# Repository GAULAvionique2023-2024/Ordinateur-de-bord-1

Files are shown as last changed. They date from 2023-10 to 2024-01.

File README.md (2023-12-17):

# ODB 1

## Description of the flight computer 1:
This board is an updated version of the first flight controler with little extra. So basicly I copy the old desing that it was an arduino shield and made it a standalone board. All the sensor is part of the board too, so no more module.All this help to make a board much smaller and more reliable. In extra I add a latching circuit too arme the board. You need to hold the button 3sec to power up the circuit and same thing to power it off. All switching is made with an mosfet so no mecanical switching excluding the power button. So the vibration can't make or break a connection and this is why the push button have an latching circuit, too avoid a false triger. Moreover I add a circuit too datalog the data on an SD card,I made a test circuit to test the 2 pyro. The circuit pass a little current (40mA) in the fuse and we mesure the voltage after so we can test for a short or open fuse. We can use this same circuit after to valid an ignition. I also add a logic circuit too avoid to put main power in the pyro when we trigger the test. It need 2 mosfet to be activate to ignite the fuse. A buzzer and a led status is also added. The board is powerd by a usb or lipo 1S(3.7v) that it can be charge by usb on the board. The RFD900 is powered by usb if its available but we will not be able to use full power only on usb so this is for testing only, on normal condition we will use an lipo 3S(11.1v). The pyro is powered by an lipo 4S(14.8v).

## Update log

### 23/12/16
All the test is now done. I corrected some mistake and change the status LED for an RGB one so it will be easier to understand its meaning. The new board its on the way.

### 23/11/22
Long time no see. Well I receive the board and do some test. All work except the GYRO and the inition of the fuse need to be confirm. I think I broke the gyro when I solder it so am waiting for a new one and in the same time im waiting for some e-fuse. I also made some minor change in the schematic and the board desing. Like switching the green status led by an RGB led, so it will be easyer to understand some status.  

### 23/10/09
Now the pcb is finish. I add the BOM file and the pcb is now on production.(see image: [ODB1_PCB](https://github.com/GAULAvionique2023-2024/Ordinateur-de-bord-1/blob/main/Images/ODB1_PCB.png))

### 23/10/01
So I rework the schematic to use less components and had the crystal circut, cause I dont know how but I was forgeting it. I also begin to layout the components on the pcb (see image: [OBD1_1_10_23](https://github.com/GAULAvionique2023-2024/Ordinateur-de-bord-1/blob/main/Images/OBD1_1_10_23.png)). I try my best to fit in the 85mmx85mm.

### 23/09/23
I add the possibility to use the RFD900 with the USB.

### 23/09/22
I can say that the schematic is now done but it will need to be verified to but sure that everything is ok and avoid poor mistake.
1.Redesing of the logic circuit protection to be more secure
2.Add a different batteries for the RFD900 so if the RFD900 drain it the pyro still have its own power.
3.In link with the second point, now the pyro is on 4s lipo (14.8v)

### 23/09/17
The schematic is almost done. Need to retink of some part of the logic part to protect the pyro cause it look like it can cause an oscilation (this part is not even up to date)
1.Add a buzzer.
2.Add poly fuse.
3.Add the logic circuit to protect the pyro. (see note on top)
4.Add latching circuit. (Hold 3s to power on/off)
5.Add many status leds. (one led can be placed externaly by a screw terminal)

This week I will try to list all the feature of this board, finalyze the schematic, add the data sheets of some ICs.

## Features
* Standalone board
* Powered by usb or lipo 1S
* Lipo charger in board
* Self test on igniter
* 2 ignitions circuits
* Gyro/Baro in board
* SD card for dataloging
* Latching circuit for powered the circuit
## Documentation
This is a list of documentation for the Ic

* [STM32F103C8](https://www.st.com/resource/en/datasheet/stm32f103c8.pdf) Main  microcontroller
* [ICM-20602](https://invensense.tdk.com/wp-content/uploads/2016/10/DS-000176-ICM-20602-v1.0.pdf) High Performance 6-Axis MEMS
* [BMP280](https://www.bosch-sensortec.com/media/boschsensortec/downloads/datasheets/bst-bmp280-ds001.pdf) Digital pressure sensor
* [L76L-M33](https://github.com/ul-gaul/Nebula-2022-2023/blob/cef41a131481a57f440abe9ede77973086518a58/WIP/Documentation/Quectel_L76_Series_Hardware_Design_V3.1.pdf) GNSS Module (GPS)
* [GT-0930RP2](https://github.com/ul-gaul/Nebula-2022-2023/blob/aa67e142a6133a87d8f8f1008be1e9982ea42536/WIP/Documentation/GT-0930RP2-14-Feb-2019.pdf) Buzzer
* [HM-10](https://github.com/ul-gaul/Nebula-2022-2023/blob/aa67e142a6133a87d8f8f1008be1e9982ea42536/WIP/Documentation/11.%20HM10%20BLE_FTDI.pdf)  BLE Module
* [TPS61201DRCR](https://www.ti.com/lit/ds/symlink/tps61201.pdf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)  Low Input Voltage Synchronous Boost Converter
* [LM1085](https://www.ti.com/lit/ds/symlink/lm1085.pdf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) 3-A Low Dropout Positive Regulators
* [max1898eub42+T](https://www.analog.com/media/en/technical-documentation/data-sheets/max1898.pdf) Linear Charger for Single-Cell Li+ Battery
* [LTC2954ITS8-1](https://www.analog.com/media/en/technical-documentation/data-sheets/2954fb.pdf) Pushbutton On/Off Controller with µP Interrup
* [CD74HC4051-EP](https://www.ti.com/lit/ds/symlink/cd74hc4051-ep.pdf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) Analog Multiplexer and Demultiplexer
* [74HC2G86DP_125](https://assets.nexperia.com/documents/data-sheet/74HC_HCT2G86.pdf) Dual 2-input EXCLUSIVE-OR gate
* [74HC2G86DP_125](https://assets.nexperia.com/documents/data-sheet/74HC_HCT2G08.pdf) Dual 2-input AND gate
* [74HC2G86DP_125](https://assets.nexperia.com/documents/data-sheet/74LVC2G02.pdf) Dual 2-input NOR gate

## Authors
List of authors
- [@Luka Dupuis](https://github.com/bestrider14)

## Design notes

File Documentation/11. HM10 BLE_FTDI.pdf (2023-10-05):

# Getting Started with the HM-10 BLE Module

### Working with the HM-10 BLE Module using UART

## Jarrod Smith

Department of Electrical and Computer Engineering

California State University, Fresno

NSF Bulldog Mote Team

## Contents

1 HM-10 BLE Module Serial Communication | 3

## List of Figures

1 | HM-10 Module from DSD Tech | | 3
2 | HM-10 Pins | | 3
3 | SH-U09F FTDI Module | | 4
4 | UART Communication Configuration | | 5
5 | Selecting Device Manager from the Start Menu | | 6
6 | Device Manager | | 7
7 | Realterm: Serial Monitor when it first starts | | 8
8 | Realterm Port Settings for FTDI Device | | 8
9 | Successful FTDI Communication in Realterm | | 9
10 | Master Discovery Readings | | 12
11 | Master (Bulldogs2) and Slave (Bulldogs) Devices Connected | | 13
12 | Master and Slave Sending Strings | | 14
13 | Master Connecting to Slave Based on MAC Address | | 15
14 | Bluetooth Adapter Disabled | | 17
15 | Scanning for BLE Devices | | 18
16 | HM-10 Services | | 19
17 | HM-10 ESS Characteristics | | 20
18 | Sending Temperature Data | | 21
19 | Temperature Reading in nRF Connect | | 22

## 1 HM-10 BLE Module Serial Communication

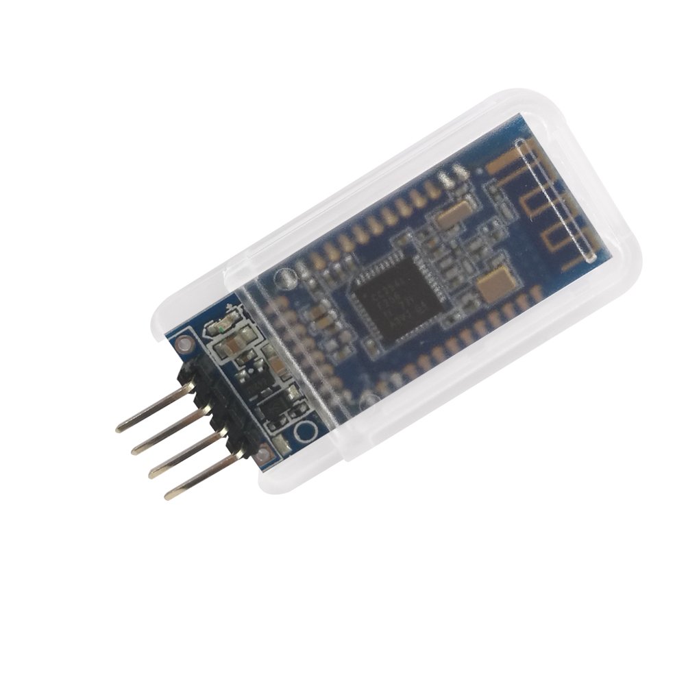
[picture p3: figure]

Figure 1: HM-10 Module from DSD Tech

The HM-10 Module is a Bluetooth 4.0 Module that includes Bluetooth Low Energy (BLE). This module transmits over the 2.4 GHz ISM band like traditional Bluetooth, however BLE uses considerably less power while still maintaining its effective communication range. This makes BLE a viable option for IoT communication between devices.

### 1.1 Overview

The BLE device communicates with a host microcontroller using UART. Depending on the supplier the device is purchased through will determine the number of pins. For this tutorial, the four middle pins will be used: RXD, TXD, GND and VDD.

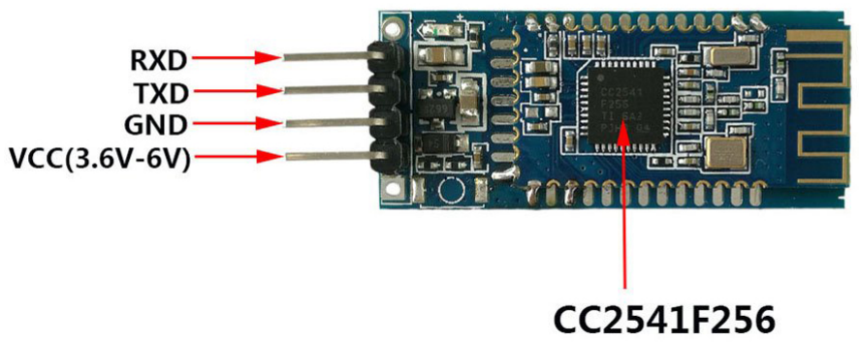
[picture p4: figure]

Figure 2: HM-10 Pins

The commands to control this device have to be understood before it is plugged into a microcontroller. To do this, an FTDI module can be used to connect the UART pins of the HM-10 directly to a computer. There, a serial connection can be established with the module and will give the user an easier time testing and debugging commands.

Any FTDI module will work, but be sure to purchase one with a genuine FTDI chip. Most computers have firmware installed already that will make these devices plug-and-play ready. However if the FTDI chip is not a genuine one, the modern firmware will be able to tell and “.*” the counterfeit chip, rendering it unusable.

The FTDI component used here is the SH-U09F, produced by DSD Tech as well.

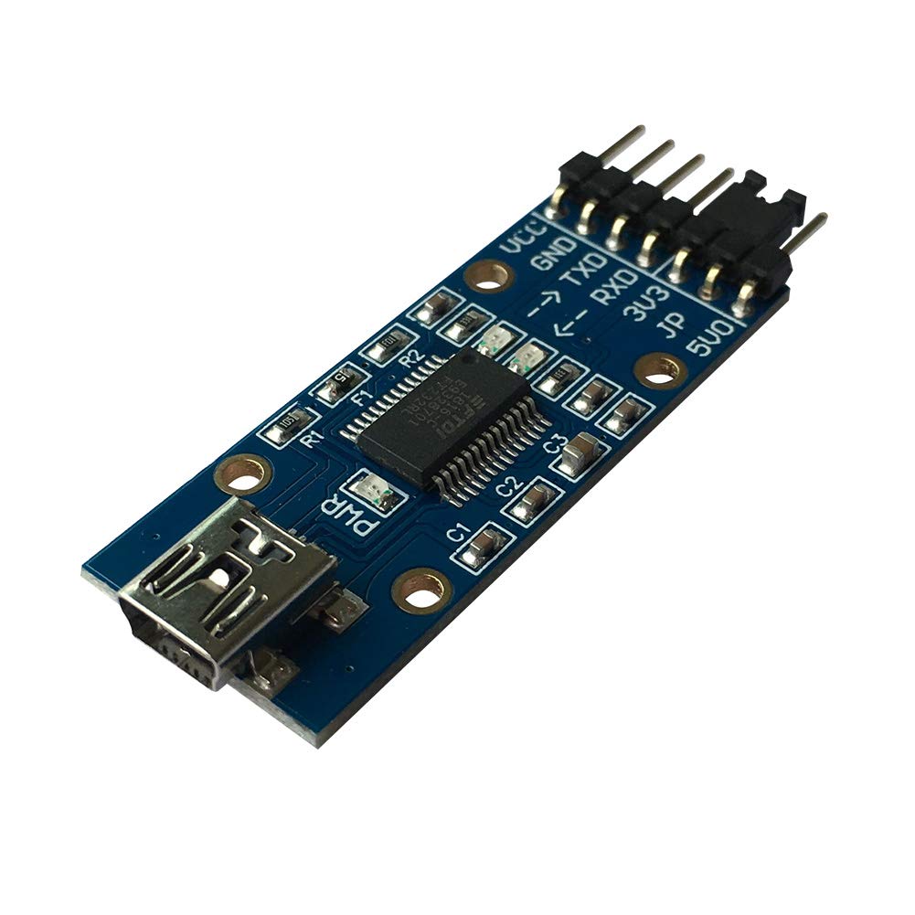
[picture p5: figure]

Figure 3: SH-U09F FTDI Module

The current drivers should be downloaded and installed before plugging the FTDI component into the computer. The current FTDI drivers can be found at http://www.ftdichip.com/Drivers/VCP.htm. (http://www.ftdichip.com/Drivers/VCP.htm) There you can select the correct firmware for your operating system. Once installed plug the device into your computer. The SH-U09F module here uses a micro USB cable to connect to the host computer.

After the computer finishes configuring the FTDI module, unplug the device. Next the FTDI module will be connected to the BLE module. The HC-10 device uses 3.3 V logic and power, so on the SH-U09F module the jumper between the 5V0 pin and JP pin should be changed to connect the 3V3 and JP pins instead. This changes the logic and VCC voltages to 3.3 V. Next, the pins of the devices can be connected with jumper wire. The following diagram should be followed:

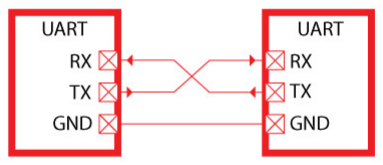
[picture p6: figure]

Figure 4: UART Communication Configuration

In UART communication, the receive line (Rx) on one device is connected to the transmit (Tx) of the other, and visa-versa. VCC and GND should also be connected.

Once connected a serial communication program can be used to send and receive data from the user’s computer to the end device on the other end of the FTDI module. The program used here to send and receive the UART data is Realterm: Serial Terminal: https://realterm.sourceforge.io/index.html#downloads_Download. Go to the link and click the download link at the top of the page to get the install executable.

Once installed and opened, the program will connect automatically to a device with a COM port. So plug in the FTDI module again, then open the Device Manager by clicking the Start menu, then type Device Manager in the Search text box. Open the Device Manager once it pops up.

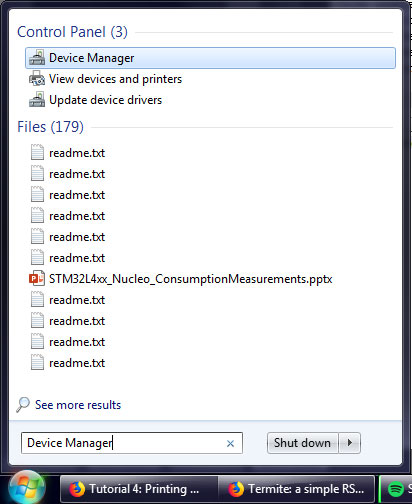
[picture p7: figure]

Figure 5: Selecting Device Manager from the Start Menu

Once opened, go to the Ports list to identify the COM number of the FTDI module. In this case it is COM11.

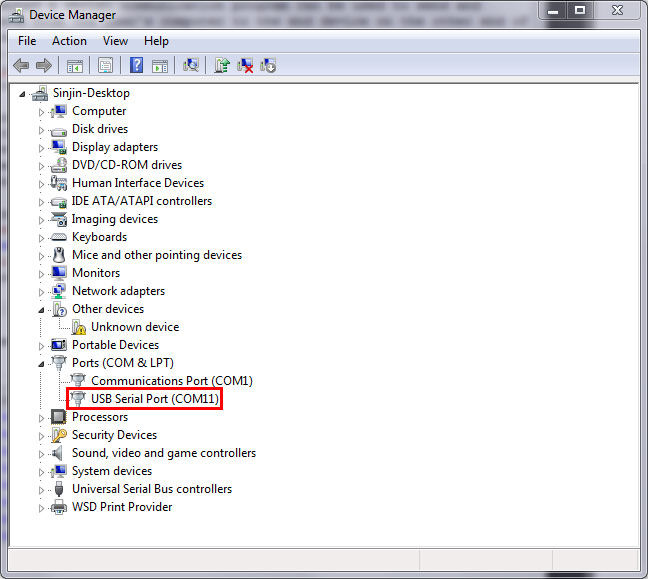
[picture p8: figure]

Figure 6: Device Manager

If there are many devices connected and it is difficult to tell which is the correct one, then right click on one of them at a time a go to Properties. Under Manufacturer should be FTDI for the correct module.

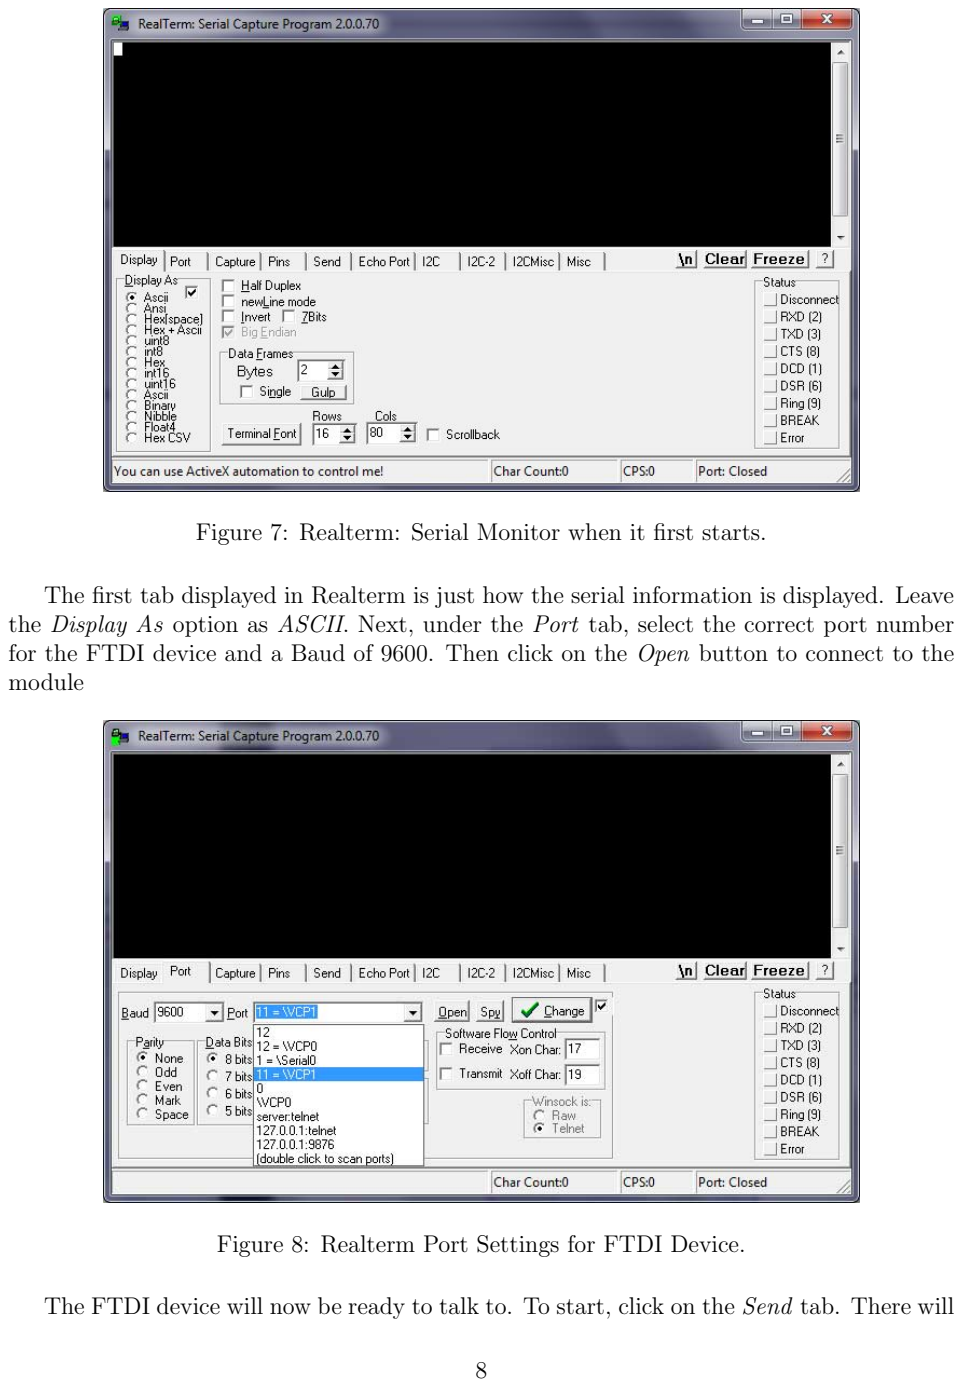
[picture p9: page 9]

Figure 7: Realterm: Serial Monitor when it first starts.

The first tab displayed in Realterm is just how the serial information is displayed. Leave the Display As option as ASCII. Next, under the Port tab, select the correct port number for the FTDI device and a Baud of 9600. Then click on the Open button to connect to the module

Figure 8: Realterm Port Settings for FTDI Device.

The FTDI device will now be ready to talk to. To start, click on the Send tab. There will be two identical lines with a text input and buttons reading Send Numbers and Send ASCII. Either of the two lines can be used to send data. There will be cases where you’ll want to send raw binary/hexadecimal data to the device where the Send Numbers will be useful. But for configuring the FTDI module ASCII encoded characters are what we need. Also, to have responses on separate lines, click the After check box in the \n section. Otherwise all the FTDI responses will run on the same line.

Now the connection can be tested. In the text box type “AT” (without quotes) and click Send ASCII. If the connection is successful there should be a response of “OK” in the window.

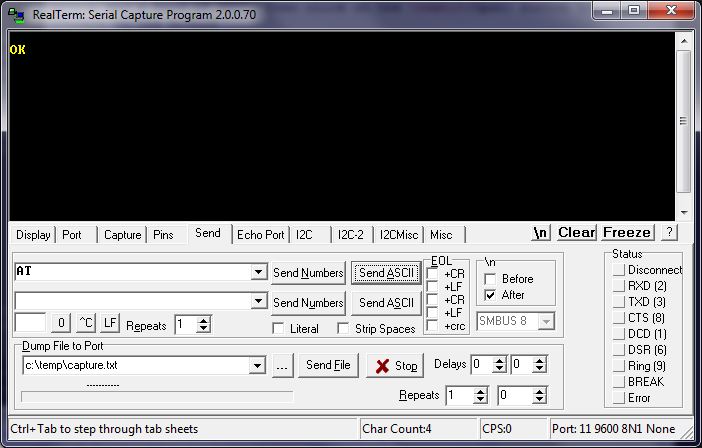
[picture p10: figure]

Figure 9: Successful FTDI Communication in Realterm.

### 1.2 HM-10 Module Configuration

Some default settings in the HM-10 module need to be changed after the module is wired up and communication is verified in Realterm.

While in Realterm, type: “AT+IMME?”. If the response is “OK+Get:0”, then type “AT+IMME1” to change the settings. This setting is used to tell the module to start in command mode or work mode when the device starts up. In command mode (changed by sending “AT+IMME1”), the component will only perform what the user asks based on the AT commands. In work mode (“AT+IMME1”), the device will automatically perform actions like connecting to neighboring devices, enabling discovery, etc. based on its current settings on start up.

Next, we’ll want to see what message the device can display, so the next command will turn on notifications: “AT+NOTI1”. Then, type “AT+NOTP1” to show MAC addresses related to the notification.

The HM-10 device likely has a default name (not the same as the MAC address). So give the device a unique name by typing “AT+NAME[name]” where “[name]” is a string. For example, if you want to name the device Bulldogs, then the command would be “AT+NAMEBulldogs”.

Next, all Bluetooth Low Energy devices use some UUID value to identify what type of information to expect in a standardized manner. To change the UUID value sent the command: “AT+UUID[uuid]” where “[uuid]” is a valid UUID value in hexadecimal with a hexadecimal prefix. For example, if you wanted to use UUID value 0x181A, which is the Bluetooth assigned number for the Environment Sensing service. For more information on the Bluetooth protocol, read the Bulldog BLE Handbook (coming soon).

Similarly, the service characteristic value can also be set on the HM-10. Under Environmental Sensing Service there are several characteristics, one of which is Temperature with a UUID of 0x2A6E. Use the command “AT+CHAR[char]” where “[char]” is the UUID value of the characteristic to set the device’s characteristic.

While the device is connected to another Bluetooth device, no AT-commands will be valid until the connection is broken. This can be done manually by simply typing “AT”. The module should return “OK+LOST” when successfully disconnected. This step should not be necessary if AT+TCON and AT+IMME are set.

### 1.3 Connecting Two HM-10 Devices

Two HM-10 devices can be connected together once the settings listed previously are changed. Actually the devices could be connected prior to running those commands, but to save a head-ache or two its advisable to run them first.

Multiple instances of Realterm can be run on the same computer so this process can be completed on a single computer with two HM-10 devices connected to it. Whether you decide to connect the other HM-10 to the same computer or not, perform the same steps in the Overview and HM-10 Module Configuration sections of this document to set up the second FTDI and HM-10 device separately.

Once both devices are setup and connected to the computer, then they can be paired and bonded. To do so takes a few steps.
First, one device must be selected as the master and the other the slave device. In Bluetooth Point-to-Point protocols, the slave device is the one with data from sensor readings and the master device is the one that connected to the slave to gather that data.

To set the master/slave roles for each device use the command “AT+ROLE”.

### 1.3.1 Setting up Slave Device

To change the role of the module to a slave use the command: “AT+ROLE0”. Doing this starts the module advertising its presence to BLE master devices. As a note, some datasheets call the slave device the Peripheral Node.

Next, to change the interval in which the slave sends an advertisement use the command: “AT+ADVI[P1]”, where [P1] is a value 0 through F and represents different time intervals in Table 1:

[P1] | Advertising Interval (ms) | [P1] | Advertising Interval (ms)
0 | 100 | 8 | 1022.5
1 | 152.5 | 9 | 1285
2 | 211.25 | A | 2000
3 | 318.75 | B | 3000
4 | 417.5 | C | 4000
5 | 546.25 | D | 5000
6 | 760 | E | 6000
7 | 852.5 | F | 7000

Table 1: ADVI Values

The default value of 1285 ms is fine for our purposes.

Also to keep in mind, there are different advertising types under the “AT+ADTY” command. The default allows advertising, scanning response and makes the device openly connectable. To set the device back to its default type use: “AT+ADTY0”.

Lastly, some device wont advertise unless the advertising data flag is set. To do this the AT+FLAG command is used. Type “AT+FLAG0” and click Send ASCII. This command can use values from 0 through FF, however using any value will get the device to advertise.

Now the slave device is advertising its presence and ready to be connected to.

### 1.3.2 Setting up Master Device

Setting up the master is a little simpler than the slave device. The command to set the device to master is “AT+ROLE1”. The master is also called the Central Node in some datasheets.

Once set the device can immediately begin scanning for slave devices. Type “AT+DISC?” to do so. If the slave is configured correctly the terminal for the master should read: “OK+DISCS” (starting discovery), then “OK+DIS0:[MACADDR]” (where [MACADDR] is the MAC address of the slave module), and finally “OK+DISCE” (for ending discovery process). Likely all of these messages will be on the same line.

If there were multiple BLE slave devices available and in range there will be a “OK+DIS1:[MACADDR]”. The important thing here is the value after OK+DIS. This value represents the array index
of the connectable BLE devices. So it will be important to know the MAC address of the
slave HM-10 module to identify which device the master should connect to.

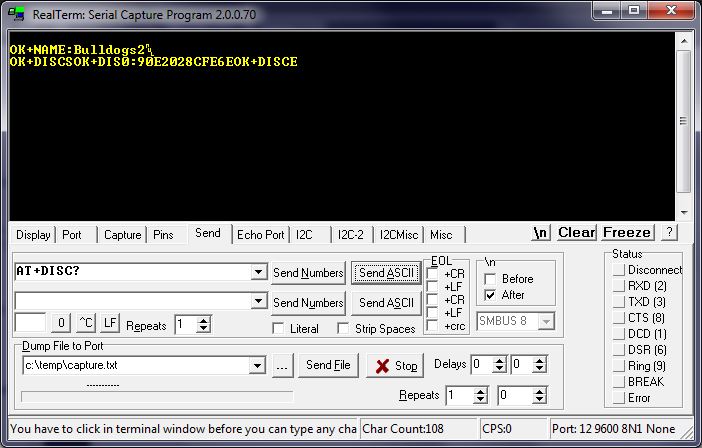
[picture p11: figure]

Figure 10: Master Discovery Readings.

### 1.3.3 Discovery Connection

From Figure 10, the slave device is identified by “OK+DIS0:90E2028CFE6E” meaning that the device with MAC address 90:E2:02:8C:FE:6E can be connected to using index 0. So now the master can connect to this discovery device using the command “AT+CONN[DISC]” where [DISC] is the array index. So in the case of Figure 10 the command would be “AT+CONN0”. Doing this connects to the slave device and shows in both devices terminals that they are connected to each others MAC addresses.

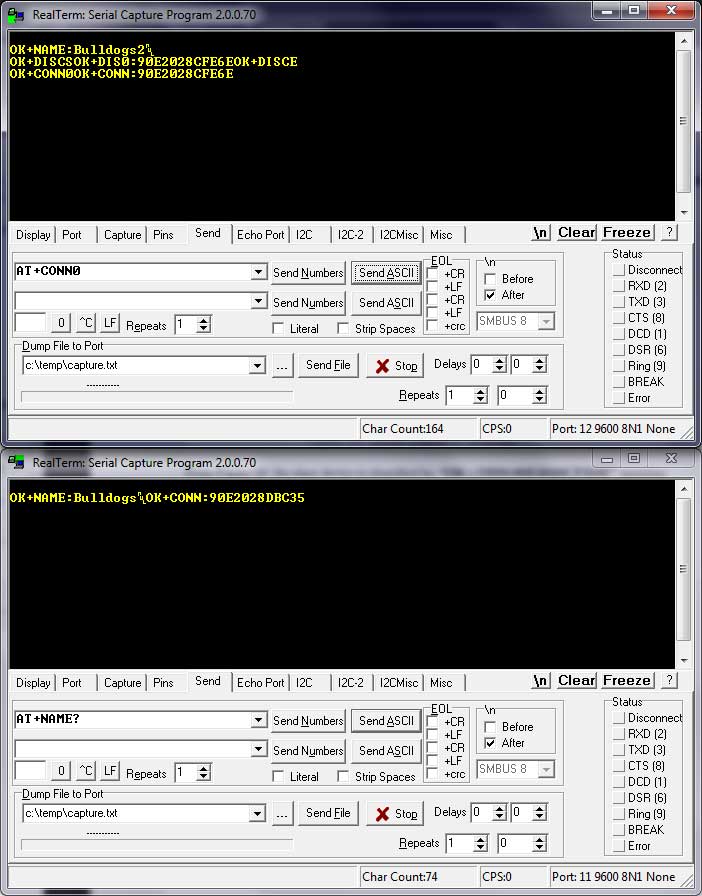
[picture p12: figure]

Figure 11: Master (Bulldogs2) and Slave (Bulldogs) Devices Connected.

Now simple strings or numbers can be transmitted from slave to master and visa-versa. In transmit mode, none of the AT commands will be recognized except the “AT” command, which disconnects both devices.

Note: Once the slave device is disconnected the advertising flag needs to be set again before it can be discovered.

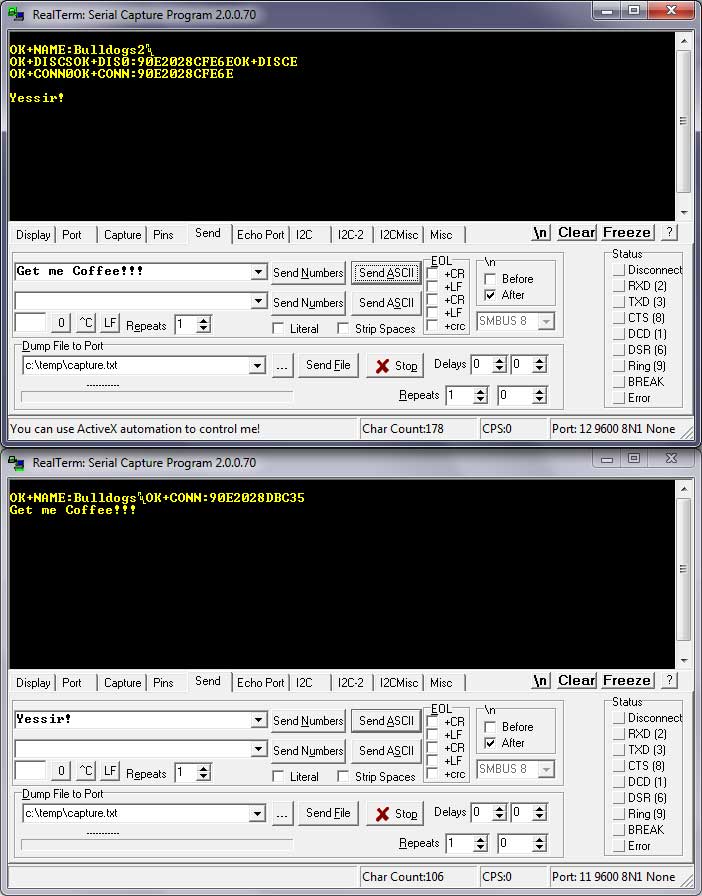
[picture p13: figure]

Figure 12: Master and Slave Sending Strings.

When connecting to a device its sometimes more desirable to connected to a device based
on its MAC address instead of discovery array index. The command “AT+CON[MACADDR]” can be used to so this from the master. The discovery command should still be run first to know if the slave device is available to be connected to first.

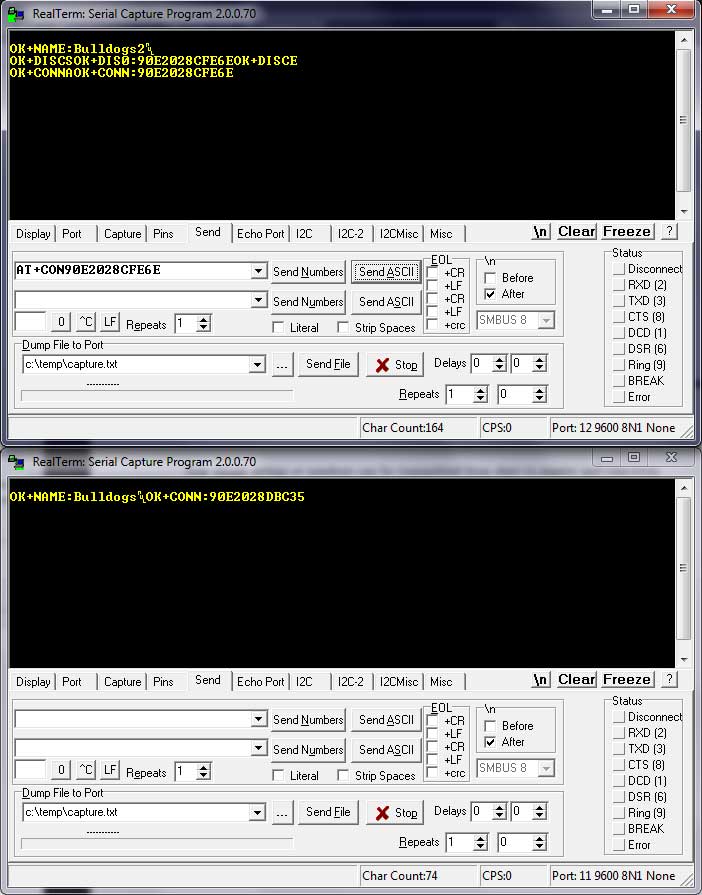
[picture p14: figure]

Figure 13: Master Connecting to Slave Based on MAC Address.

### 1.4 Connecting to HM-10 from Android Phone

In the last part, two HM-10 devices were connected, one being the master and the other the slave. In this part, one HM-10 module will be used as a slave device and a smart phone will be used as the master device. This part completely depends on the capabilities of your smart phone. Make sure your phone has BLE capabilities to be able to do this.

If the phone does have BLE capabilities, the nRF Connect can be downloaded from the Google Play Store. nRF Connect is an app by Nordic Semiconductor used to connect and communication to any BLE device.

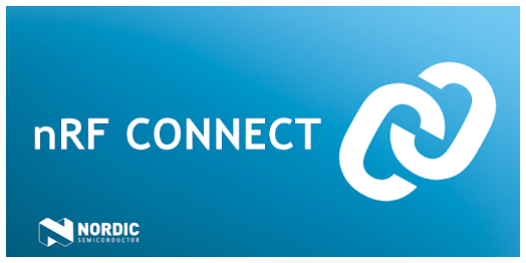
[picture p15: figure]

First however, one of the HM-10 modules should be set up as a slave device as shown in the last section. In addition, the UUID for the slave device’s service and characteristic should be configured as described in the HM-10 Module Configuration. Make sure to reset the module after making changes to apply them using the “AT+RESET” command.

Once the slave device is set up and advertising its presence, the Android device can detect and connect to it. To do so, install and open the nRF Connect app. If the Bluetooth adapter is disabled it there will be a red bar instructing you to enable it.

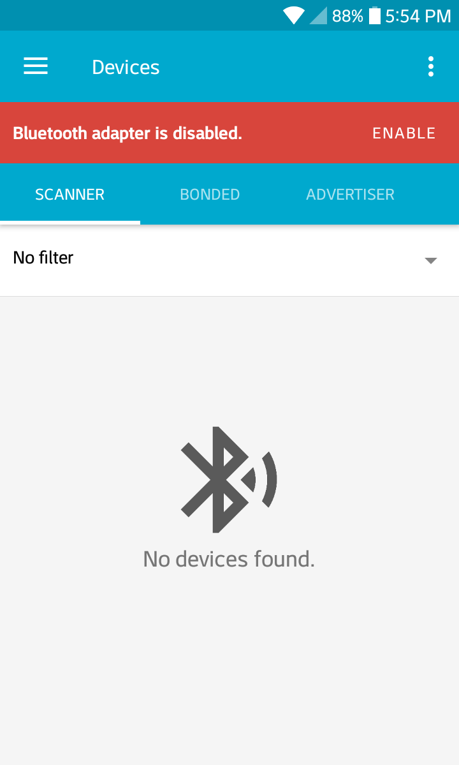
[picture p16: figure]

Figure 14: Bluetooth Adapter Disabled.

Once enabled, click the Scan button on the top right. After a moment, the HM-10 device should show up with its name.

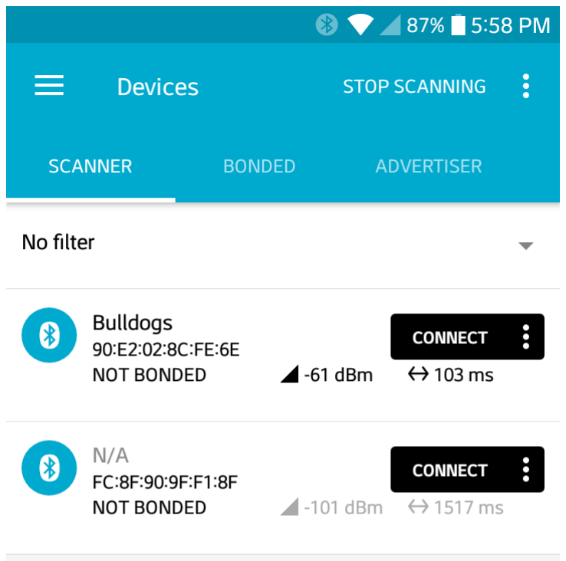
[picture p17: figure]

Figure 15: Scanning for BLE Devices.

Click on the Connect button on the HM-10 device. Doing this will open a new tab will open with the name of the module. In this tab there are three main services, two generic services and one Environmental Sensing. Click on the Environmental Sensing service. If the UUIDs were set up correctly, the values used in the configuration were for the Bluetooth Environment Sensing Service (ESS) and Temperature Characteristic within the ESS.

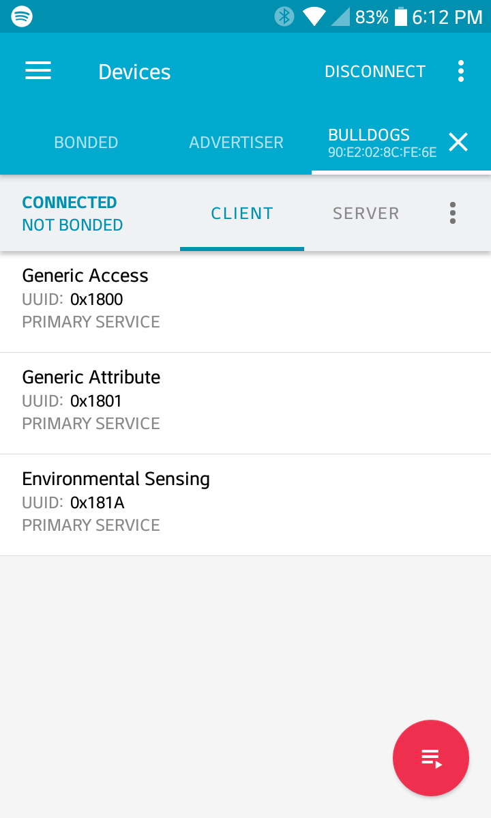
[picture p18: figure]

Figure 16: HM-10 Services.

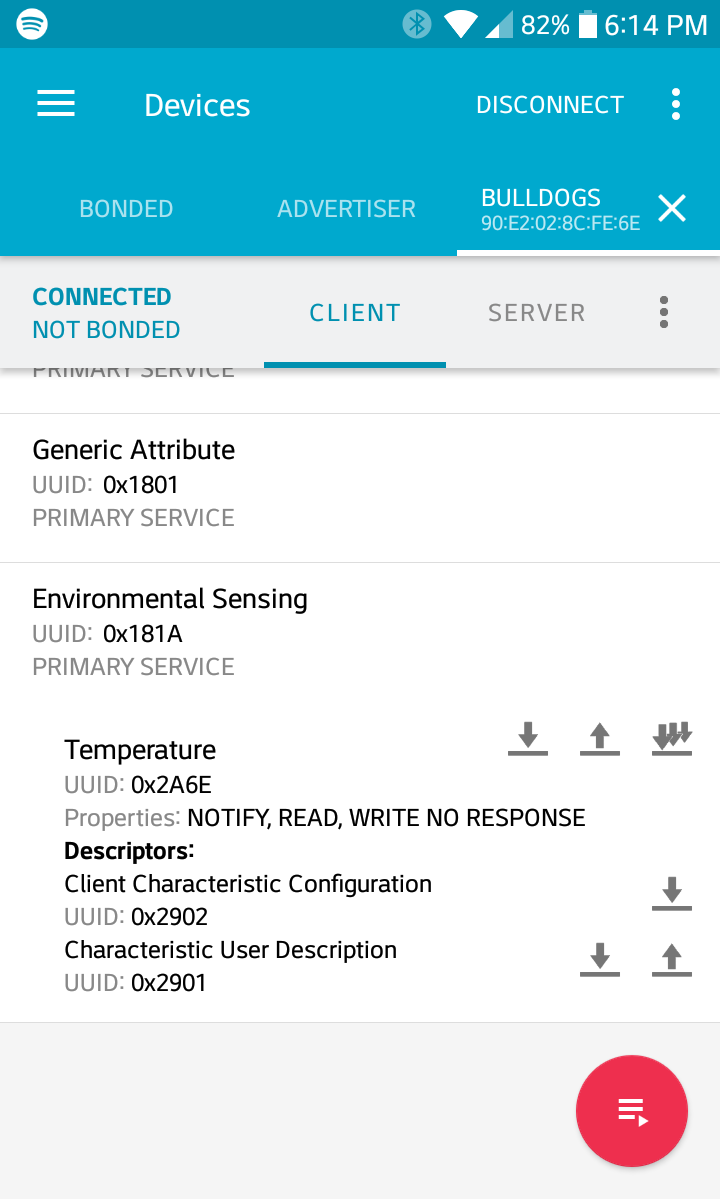
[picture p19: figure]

Figure 17: HM-10 ESS Characteristics.

However, there is no data for the temperature reading yet. We don’t have an actual temperature sensor connected to the BLE module, so we’ll have to fake it for now.

The temperature value can be transmitted from Realterm in the form of raw hexadecimal values. Bluetooth gives specifications for formatting data for all characteristics. The ESS Specification for the Temperature Characteristic allows a degree resolution down to 0.01◦C. Also, the data type of the value is an sint16, or 16-bit signed-integer. To fix the decimal point problem that would be lost in using a integer the temperature value needs to be multiplied by 10² before being converted into signed-integer. So a temperature reading of 34.56◦C would be 3456 and 0x0D80 in hexadecimal. Also, signed-integers used Two’s Compliment to represent negative values. Thus, a temperature reading of -10.35◦C would be multiplied by 10² and converted to Two’s Compliment to get a result of 0xFBF5.

So lets use the temperature value of 34.56◦C to send to the Android device connected to the HM-10. In Realterm we can send these values in their signed-integer, hexadecimal form with a couple things to consider. During the UART transmission, the Endianness of the bytes of the numbers are reversed, so the byte order will need to be fixed manually. Also in Realterm, each byte has to be expressed individually with a prefix, so 0x0D80 would need to be sent as 0x0D and 0x80. And if we take into consideration the byte reversal then 0x0D80 becomes 0x80 and 0x0D.

So with this in mind, go to Realterm and in the Send tab, type “0x80 0x0D” in the input box. Then instead of clicking Send ASCII, click Send Numbers instead to send the raw hexadecimal values.

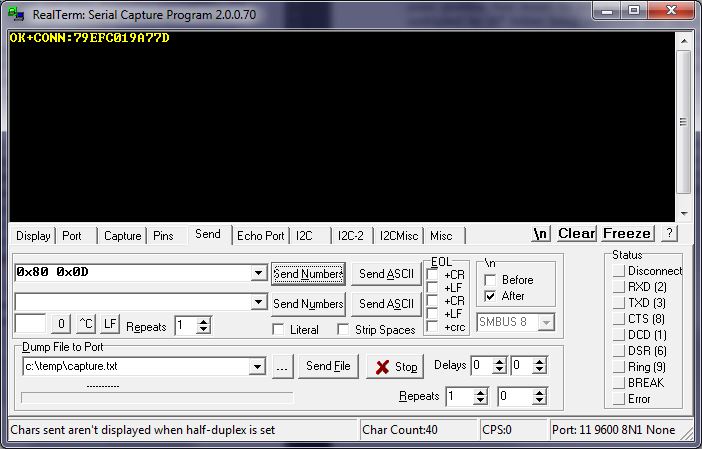
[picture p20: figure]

Figure 18: Sending Temperature Data.

Now checking the Andriod device, it can be seen that a Value line appears with the temperature reading of 34.56◦C:

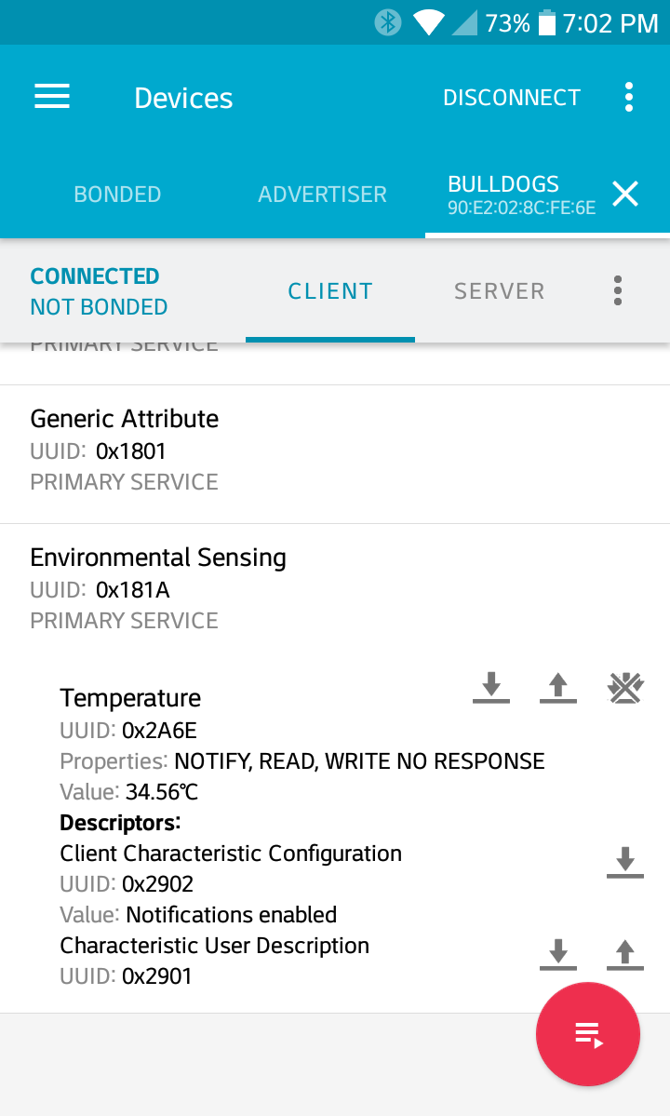
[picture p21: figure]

Figure 19: Temperature Reading in nRF Connect.

## References

- JNHuaMao Technology Company, ”HM Bluetooth module datasheet,” Bluetooth 4.0 BLE module Datasheet, Mar. 2015.
- ”GATT Services”, Bluetooth.com, 2019. [Online]. Available: https://www.bluetooth.com/specifications/gatt/services/.
- M. Currey, ”HM-10 Bluetooth 4 BLE Modules”, Martyncurrey.com, 2017. [Online]. Available: http://www.martyncurrey.com/hm-10-bluetooth-4ble-modules/.

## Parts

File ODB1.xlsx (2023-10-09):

Country of Origin may be different at time of shipment.
The HTSUS and ECCN information shown is for informational purposes only and is not a representation or warranty as to the accuracy or reliability of these classifications. All information is provided "as is" and is subject to change without notice. Any use made of the information provided is without recourse to Digi-Key and at the user's risk.
Index | Manufacturer Part Number | Manufacturer Name | Description | Availability | Stock Status | Attrition % | Requested Quantity 1 | Pack Quantity 1 | Pack Type 1 | Digi-Key Part Number 1 | Unit Price 1 | Extended Price 1 | Minimum Order Quantity 1 | Customer Reference | Requested Part Number | Lead Weeks | Datasheet | Reference Designator | US Import Tariff | Note | Part Status | RoHS Status | Moisture Sensitivity Level (MSL) | ECCN | HTSUS | Country of Origin | Environmental Information | Original Part numbers | Image
1 | RC0805JR-0756KL | YAGEO | RES 56K OHM 5% 1/8W 0805 | 11,677 | In Stock |  | 10 | 10 | Cut Tape (CT) | 311-56KARCT-ND | 0.03500 | $0.35 | 1 |  | 311-56KARCT-ND | 18 | https://www.yageo.com/upload/media/product/productsearch/datasheet/rchip/PYu-RC_Group_51_RoHS_L_12.pdf |  | May apply on shipments to the U.S. |  | Active | ROHS3 Compliant | 1 (Unlimited) | EAR99 | 8533.21.0030 | China | https://www.yageo.com/en/Download/Index/certificates#rchip | 311-56KARCT-ND | https://mm.digikey.com/Volume0/opasdata/d220001/medias/images/4848/13_0805-(2012-metric).jpg
2 | RC0805FR-07100KL | YAGEO | RES 100K OHM 1% 1/8W 0805 | 2,675 | In Stock |  | 10 | 10 | Cut Tape (CT) | 311-100KCRCT-ND | 0.03700 | $0.37 | 1 |  | 311-100KCRCT-ND | 18 | https://www.yageo.com/upload/media/product/app/datasheet/rchip/pyu-rc_group_51_rohs_l.pdf |  | May apply on shipments to the U.S. |  | Active | ROHS3 Compliant | 1 (Unlimited) | EAR99 | 8533.21.0030 | Taiwan | https://www.yageo.com/en/Download/Index/certificates#rchip | 311-100KCRCT-ND | https://mm.digikey.com/Volume0/opasdata/d220001/medias/images/4848/13_0805-(2012-metric).jpg
3 | RC0805FR-071KL | YAGEO | RES 1K OHM 1% 1/8W 0805 | 587 | In Stock |  | 18 | 18 | Cut Tape (CT) | 311-1.00KCRCT-ND | 0.03700 | $0.67 | 1 |  | 311-1.00KCRCT-ND | 18 | https://www.yageo.com/upload/media/product/app/datasheet/rchip/pyu-rc_group_51_rohs_l.pdf |  | May apply on shipments to the U.S. |  | Active | ROHS3 Compliant | 1 (Unlimited) | EAR99 | 8533.21.0030 | Taiwan | https://www.yageo.com/en/Download/Index/certificates#rchip | 311-1.00KCRCT-ND | https://mm.digikey.com/Volume0/opasdata/d220001/medias/images/4848/13_0805-(2012-metric).jpg
4 | RC0805JR-0727KL | YAGEO | RES 27K OHM 5% 1/8W 0805 | 5,772 | In Stock |  | 1 | 1 | Cut Tape (CT) | 311-27KARCT-ND | 0.15000 | $0.15 | 1 |  | 311-27KARCT-ND | 18 | https://www.yageo.com/upload/media/product/productsearch/datasheet/rchip/PYu-RC_Group_51_RoHS_L_12.pdf |  | May apply on shipments to the U.S. |  | Active | ROHS3 Compliant | 1 (Unlimited) | EAR99 | 8533.21.0030 | Taiwan | https://www.yageo.com/en/Download/Index/certificates#rchip | 311-27KARCT-ND | https://mm.digikey.com/Volume0/opasdata/d220001/medias/images/4848/13_0805-(2012-metric).jpg
5 | RC0805JR-0710KL | YAGEO | RES 10K OHM 5% 1/8W 0805 | 167 | In Stock |  | 17 | 17 | Cut Tape (CT) | 311-10KARCT-ND | 0.03400 | $0.58 | 1 |  | 311-10KARCT-ND | 18 | https://www.yageo.com/upload/media/product/app/datasheet/rchip/pyu-rc_group_51_rohs_l.pdf |  | May apply on shipments to the U.S. |  | Active | ROHS3 Compliant | 1 (Unlimited) | EAR99 | 8533.21.0030 | Taiwan | https://www.yageo.com/en/Download/Index/certificates#rchip | 311-10KARCT-ND | https://mm.digikey.com/Volume0/opasdata/d220001/medias/images/4848/13_0805-(2012-metric).jpg
6 | MMBT3904-TP | Micro Commercial Co | TRANS NPN 40V 0.2A SOT23 | 1,448 | In Stock |  | 4 | 4 | Cut Tape (CT) | MMBT3904TPMSCT-ND | 0.15000 | $0.60 | 1 |  | MMBT3904TPMSCT-ND | 10 | https://www.mccsemi.com/pdf/Products/MMBT3904(SOT-23).pdf |  | May apply on shipments to the U.S. |  | Active | ROHS3 Compliant | 1 (Unlimited) | EAR99 | 8541.21.0075 | China | https://www.mccsemi.com/pdf/pbfree/Certification%20of%20Compliance%20of%20CaliforniaProposition65.pdf|https://www.mccsemi.com/pdf/pbfree/Certification%20of%20REACH%20Compliance.pdf|https://www.mccsemi.com/pdf/pbfree/Certification%20of%20RoHS%20Compliance.pdf | MMBT3904TPMSCT-ND | https://mm.digikey.com/Volume0/opasdata/d220001/medias/images/5357/MFG_BC817-16-TP.jpg
7 | RC0805JR-0736KL | YAGEO | RES 36K OHM 5% 1/8W 0805 | 10,117 | In Stock |  | 2 | 2 | Cut Tape (CT) | 311-36KARCT-ND | 0.15000 | $0.30 | 1 |  | 311-36KARCT-ND | 18 | https://www.yageo.com/upload/media/product/app/datasheet/rchip/pyu-rc_group_51_rohs_l.pdf |  | May apply on shipments to the U.S. |  | Active | ROHS3 Compliant | 1 (Unlimited) | EAR99 | 8533.21.0030 | Taiwan | https://www.yageo.com/en/Download/Index/certificates#rchip | 311-36KARCT-ND | https://mm.digikey.com/Volume0/opasdata/d220001/medias/images/4848/13_0805-(2012-metric).jpg
8 | C0805X103K1RAC3316 | KEMET | CAP CER 0805 10NF 100V X7R | 7,594 | In Stock |  | 4 | 4 | Cut Tape (CT) | 399-C0805X103K1RAC3316CT-ND | 0.24000 | $0.96 | 1 |  | 399-C0805X103K1RAC3316CT-ND | 16 | https://connect.kemet.com:7667/gateway/IntelliData-ComponentDocumentation/1.0/download/datasheet/C0805X103K1RAC3316 |  | N/A |  | Active | ROHS3 Compliant | 1 (Unlimited) | EAR99 | 8532.24.0020 | Mexico |  | 399-C0805X103K1RAC3316CT-ND | https://mm.digikey.com/Volume0/opasdata/d220001/medias/images/423/0805-(2012-Metric)-2,00x1,20x1,00mm.jpg
9 | RMCF0805JT1K10 | Stackpole Electronics Inc | RES 1.1K OHM 5% 1/8W 0805 | 2,312 | In Stock |  | 10 | 10 | Cut Tape (CT) | RMCF0805JT1K10CT-ND | 0.02400 | $0.24 | 1 |  | RMCF0805JT1K10CT-ND | 15 | https://www.seielect.com/catalog/sei-rmcf_rmcp.pdf |  | May apply on shipments to the U.S. |  | Active | ROHS3 Compliant | 1 (Unlimited) | EAR99 | 8533.21.0030 | Taiwan | https://www.seielect.com/catalog/cert-of-compliance.pdf|https://www.seielect.com/catalog/reach.pdf|https://www.seielect.com/catalog/SEI-RoHS_Compliance_Status.pdf | RMCF0805JT1K10CT-ND | https://mm.digikey.com/Volume0/opasdata/d220001/medias/images/639/0805-RMCF-Series.jpg
10 | ERJ-6ENF10R0V | Panasonic Electronic Components | RES SMD 10 OHM 1% 1/8W 0805 | 1,463 | In Stock |  | 11 | 11 | Cut Tape (CT) | P10.0CCT-ND | 0.07900 | $0.87 | 1 |  | P10.0CCT-ND | 21 | https://industrial.panasonic.com/cdbs/www-data/pdf/RDA0000/AOA0000C304.pdf |  | May apply on shipments to the U.S. |  | Active | ROHS3 Compliant | 1 (Unlimited) | EAR99 | 8533.21.0030 | China | https://industrial.panasonic.com/cdbs/www-cgi/auto-publishing.cgi?type=ROSU&region=WW&layer=4&cd=AOA0002 | P10.0CCT-ND | https://mm.digikey.com/Volume0/opasdata/d220001/medias/images/2502/ERJ-0805 Pkg.jpg
11 | CL21B106KOQNNNG | Samsung Electro-Mechanics | CAP CER 10UF 16V X7R 0805 | 2,059 | In Stock |  | 12 | 12 | Cut Tape (CT) | 1276-6472-1-ND | 0.25100 | $3.01 | 1 |  | 1276-6472-1-ND | 22 | http://www.samsungsem.com/kr/support/product-search/mlcc/CL21B106KOQNNNG.jsp |  | N/A |  | Active | ROHS3 Compliant | 1 (Unlimited) | EAR99 | 8532.24.0020 | China | https://www.samsungsem.com/files/fileDown.do?key=ed1dfdfa-645e-4252-b707-17f9b1502dd1|https://www.samsungsem.com/global/support/certificate/product-stewardship.do | 1276-6472-1-ND | https://mm.digikey.com/Volume0/opasdata/d220001/medias/images/2537/Ceramic-Capacitor-CL-Series.jpg
12 | C0805C104M5RAC7800 | KEMET | CAP CER 0.1UF 50V X7R 0805 | 2,020 | In Stock |  | 50 | 50 | Cut Tape (CT) | 399-C0805C104M5RAC7800CT-ND | 0.04380 | $2.19 | 1 |  | 399-C0805C104M5RAC7800CT-ND | 19 | https://connect.kemet.com:7667/gateway/IntelliData-ComponentDocumentation/1.0/download/datasheet/C0805C104M5RACTU |  | May apply on shipments to the U.S. |  | Active | ROHS3 Compliant | 1 (Unlimited) | EAR99 | 8532.24.0020 | Taiwan |  | 399-C0805C104M5RAC7800CT-ND | https://mm.digikey.com/Volume0/opasdata/d220001/medias/images/423/0805-(2012-Metric)-2,00x1,20x1,00mm.jpg
13 | RC0805FR-0730RL | YAGEO | RES 30 OHM 1% 1/8W 0805 | 6,814 | In Stock |  | 1 | 1 | Cut Tape (CT) | 311-30.0CRCT-ND | 0.15000 | $0.15 | 1 |  | 311-30.0CRCT-ND | 18 | https://www.yageo.com/upload/media/product/app/datasheet/rchip/pyu-rc_group_51_rohs_l.pdf |  | May apply on shipments to the U.S. |  | Active | ROHS3 Compliant | 1 (Unlimited) | EAR99 | 8533.21.0030 | Taiwan | https://www.yageo.com/en/Download/Index/certificates#rchip | 311-30.0CRCT-ND | https://mm.digikey.com/Volume0/opasdata/d220001/medias/images/4848/13_0805-(2012-metric).jpg
14 | GT-0930RP2 | Soberton Inc. | BUZZER MAGNETIC 3V 9MM TH | 85,460 | In Stock |  | 1 | 1 | Bulk | 433-1013-ND | 1.42000 | $1.42 | 1 |  | 433-1013-ND | 3 | https://www.soberton.com/wp-content/uploads/2019/02/GT-0930RP2-14-Feb-2019.pdf |  | May apply on shipments to the U.S. |  | Active | ROHS3 Compliant | Not Applicable | EAR99 | 8531.80.9041 | China | https://3v3a381mwao0wqrxz1y375ju-wpengine.netdna-ssl.com/wp-content/uploads/2021/02/SOBERTON-211-REACH-SVHC.pdf|https://www.soberton.com/wp-content/uploads/2019/10/RoHS-3.0-CoC-2019.pdf | 433-1013-ND | https://mm.digikey.com/Volume0/opasdata/d220001/medias/images/661/GT-0930RP2.jpg
15 | B260A-13-F | Diodes Incorporated | DIODE SCHOTTKY 60V 2A SMA | 94 | In Stock |  | 3 | 3 | Cut Tape (CT) | B260A-FDICT-ND | 0.64000 | $1.92 | 1 |  | B260A-FDICT-ND | 8 | https://www.diodes.com/assets/Datasheets/B220_A-B260_A.pdf |  | N/A |  | Active | ROHS3 Compliant | 1 (Unlimited) | EAR99 | 8541.10.0080 | Taiwan | https://www.diodes.com/assets/Quality-Reliability-Docs/Master_CofC.pdf | B260A-FDICT-ND | https://mm.digikey.com/Volume0/opasdata/d220001/medias/images/5038/SMA6JXXCAQ--Top.jpg
16 | SP0503BAHTG | Littelfuse Inc. | TVS DIODE 5.5VWM 8.5VC SOT143-4 | 3,413 | In Stock |  | 2 | 2 | Cut Tape (CT) | F2715CT-ND | 1.23000 | $2.46 | 1 |  | F2715CT-ND | 11 | https://www.littelfuse.com/~/media/electronics/datasheets/tvs_diode_arrays/littelfuse_tvs_diode_array_sp05_datasheet.pdf.pdf |  | May apply on shipments to the U.S. |  | Active | ROHS3 Compliant | 1 (Unlimited) | EAR99 | 8541.10.0080 | China | https://www.littelfusebusinesscenter.com/LFWeb/rohs_upload/RoHS_Certificate_of_Compliance/CoC_RoHS10_SP0503BAHTG_06-25-2019.pdf | F2715CT-ND | https://mm.digikey.com/Volume0/opasdata/d220001/medias/images/4819/SOT143.jpg
17 | SP0504BAHTG | Littelfuse Inc. | TVS DIODE 5.5VWM 8.5VC SOT23-5 | 5,051 | In Stock |  | 1 | 1 | Cut Tape (CT) | F3157CT-ND | 1.26000 | $1.26 | 1 |  | F3157CT-ND | 11 | https://www.littelfuse.com/~/media/electronics/datasheets/tvs_diode_arrays/littelfuse_tvs_diode_array_sp05_datasheet.pdf.pdf |  | N/A |  | Active | ROHS3 Compliant | 1 (Unlimited) | EAR99 | 8541.10.0080 | Malaysia | https://www.littelfusebusinesscenter.com/LFWeb/rohs_upload/RoHS_Certificate_of_Compliance/CoC_RoHS10_SP0504BAHTG_08-02-2017.pdf | F3157CT-ND | https://mm.digikey.com/Volume0/opasdata/d220001/medias/images/4819/SOT25.jpg
18 | MMSZ4691-TP | Micro Commercial Co | DIODE ZENER 6.2V 500MW SOD123 | 2,606 | In Stock |  | 1 | 1 | Cut Tape (CT) | MMSZ4691-TPMSCT-ND | 0.17000 | $0.17 | 1 |  | MMSZ4691-TPMSCT-ND | 12 | https://www.mccsemi.com/pdf/Products/MMSZ4678-MMSZ4716(SOD-123).pdf |  | May apply on shipments to the U.S. |  | Active | ROHS3 Compliant | 1 (Unlimited) | EAR99 | 8541.10.0050 | China | https://www.mccsemi.com/pdf/pbfree/Certification%20of%20Compliance%20of%20CaliforniaProposition65.pdf|https://www.mccsemi.com/pdf/pbfree/Certification%20of%20REACH%20Compliance.pdf|https://www.mccsemi.com/pdf/pbfree/Certification%20of%20RoHS%20Compliance.pdf | MMSZ4691-TPMSCT-ND | https://mm.digikey.com/Volume0/opasdata/d220001/medias/images/5349/MFG_MMSZ4691-TP.jpg
19 | 0ZCH0075AF2E | Bel Fuse Inc. | PTC RESET FUSE 24V 750MA 1210 | 3,041 | In Stock |  | 2 | 2 | Cut Tape (CT) | 507-1788-1-ND | 0.34000 | $0.68 | 1 |  | 507-1788-1-ND | 14 | https://www.belfuse.com/resources/datasheets/circuitprotection/ds-cp-0zch-series.pdf |  | N/A |  | Active | ROHS3 Compliant | 2A (4 Weeks) | EAR99 | 8533.40.8070 | Taiwan | https://www.belfuse.com:443/resource-center/quality-environmental/documents/bel%20fuse/environmental/REACH%20SVHC%20201%20Declaration.pdf|https://www.belfuse.com/resource-center/quality-environmental/documents/bel%20fuse/environmental/Declaration%20of%20EU%20RoHS%20Compliance.pdf | 507-1788-1-ND | https://mm.digikey.com/Volume0/opasdata/d220001/medias/images/2574/OZCH-1210-CONCAVE SERIES.jpg
20 | RGEF1400 | Littelfuse Inc. | PTC RESET FUSE 16V 14A RADIAL | 2,294 | In Stock |  | 1 | 1 | Bag | RGEF1400HF-ND | 1.91000 | $1.91 | 1 |  | RGEF1400HF-ND | 15 | https://www.littelfuse.com/~/media/electronics/product_specifications/resettable_ptcs/littelfuse_ptc_rgef1400_product_specification.pdf.pdf |  | May apply on shipments to the U.S. |  | Active | ROHS3 Compliant | Not Applicable | EAR99 | 8533.40.8070 | China |  | RGEF1400HF-ND | https://mm.digikey.com/Volume0/opasdata/d220001/medias/images/4849/18_RGEF1400.jpg
21 | 2508051217Y6 | Fair-Rite Products Corp. | FERRITE BEAD 120 OHM 0805 1LN | 3,165 | In Stock |  | 3 | 3 | Cut Tape (CT) | 1934-1472-1-ND | 0.15000 | $0.45 | 1 |  | 1934-1472-1-ND | 18 | https://www.fair-rite.com/wp-content/themes/fair-rite/print_product.php?pid=19226 |  | May apply on shipments to the U.S. |  | Active | ROHS3 Compliant | 1 (Unlimited) | EAR99 | 8548.00.0000 | China | https://www.fair-rite.com/wp-content/uploads/2022/01/REACH-SVHC-Free-Declaration-Statement.pdf|https://www.fair-rite.com/wp-content/uploads/2020/03/RoHS-C-of-C-Declaration-Statement.pdf | 1934-1472-1-ND | https://mm.digikey.com/Volume0/opasdata/d220001/medias/images/740/25;0805(2012)-2x1,25x0,9.JPG
22 | C0805C105K4RAC7800 | KEMET | CAP CER 1UF 16V X7R 0805 | 660 | In Stock |  | 1 | 1 | Cut Tape (CT) | 399-C0805C105K4RAC7800CT-ND | 0.19000 | $0.19 | 1 |  | 399-C0805C105K4RAC7800CT-ND | 13 | https://connect.kemet.com:7667/gateway/IntelliData-ComponentDocumentation/1.0/download/datasheet/C0805C105K4RACTU |  | N/A |  | Active | ROHS3 Compliant | 1 (Unlimited) | EAR99 | 8532.24.0020 | Taiwan |  | 399-C0805C105K4RAC7800CT-ND | https://mm.digikey.com/Volume0/opasdata/d220001/medias/images/423/0805-(2012-Metric)-2,00x1,20x1,00mm.jpg
23 | RF2-04A-T-00-50-G | Adam Tech | CONN SMA JACK STR 50 OHM PCB | 8,924 | In Stock |  | 1 | 1 | Bag | 2057-RF2-04A-T-00-50-G-ND | 2.64000 | $2.64 | 1 |  | 2057-RF2-04A-T-00-50-G-ND | 14 | https://app.adam-tech.com/products/download/data_sheet/219105/rf2-04a-t-00-50-g-data-sheet.pdf |  | N/A |  | Active | ROHS3 Compliant | 1 (Unlimited) | EAR99 | 8536.69.4010 | Taiwan |  | 2057-RF2-04A-T-00-50-G-ND | https://mm.digikey.com/Volume0/opasdata/d220001/medias/images/695/RF2-04A-T-00-50-G.JPG
24 | 20021311-00010T4LF | Amphenol ICC (FCI) | CONN RCPT 10POS 0.05 GOLD PCB | 17,019 | In Stock |  | 1 | 1 | Tube | 609-3754-ND | 1.59000 | $1.59 | 1 |  | 609-3754-ND | 8 | https://mm.digikey.com/Volume0/opasdata/d220001/medias/docus/2587/Minitek 127_Catalog.pdf |  | May apply on shipments to the U.S. |  | Active | RoHS Compliant | 1 (Unlimited) | EAR99 | 8536.69.4040 | China |  | 609-3754-ND | https://mm.digikey.com/Volume0/opasdata/d220001/medias/images/1088/20021311-00010T4LF.jpg
25 | MEM2067-02-180-00-A | GCT | MICRO SD HINGED, SMT, 1.80MM PRO | 99 | In Stock |  | 1 | 1 | Cut Tape (CT) | 2073-MEM2067-02-180-00-ACT-ND | 1.65000 | $1.65 | 1 |  | 2073-MEM2067-02-180-00-ACT-ND | 9 | https://gct.co/files/specs/mem2067-spec.pdf |  | May apply on shipments to the U.S. |  | Active | ROHS3 Compliant | Not Applicable | EAR99 | 8536.69.4040 | China | https://gct.co/files/info/gct_certificate_of_compliance.pdf | 2073-MEM2067-02-180-00-ACT-ND | https://mm.digikey.com/Volume0/opasdata/d220001/medias/images/322/MFG_MEM2067-02-180-00-A.jpg
26 | 1050170001 | Molex | CONN RCPT USB2.0 MICRO B SMD R/A | 1,539 | In Stock |  | 1 | 1 | Cut Tape (CT) | WM1399CT-ND | 1.45000 | $1.45 | 1 |  | WM1399CT-ND | 12 | https://www.molex.com/pdm_docs/sd/1050170001_sd.pdf |  | May apply on shipments to the U.S. |  | Active | ROHS3 Compliant | 1 (Unlimited) | EAR99 | 8536.69.4040 | China | https://www.molex.com/datasheets/rohspdf/1050170001_rohs.pdf | WM1399CT-ND | https://mm.digikey.com/Volume0/opasdata/d220001/medias/images/631/1050170001.jpg
27 | 691137710002 | Würth Elektronik | TERM BLK 2POS SIDE ENTRY 5MM PCB | 12,652 | In Stock |  | 2 | 2 | Box | 732-10955-ND | 0.59000 | $1.18 | 1 |  | 732-10955-ND | 24 | https://www.we-online.com/katalog/datasheet/691137710002.pdf |  | N/A |  | Active | ROHS3 Compliant | Not Applicable | EAR99 | 8536.69.4040 | Italy | http://mm.digikey.com/Volume0/opasdata/d220001/medias/docus/744/Certificate_of_Compliance_ROHS.pdf | 732-10955-ND | https://mm.digikey.com/Volume0/opasdata/d220001/medias/images/2380/MFG_691137710002.jpg
28 | LQH3NPN3R3MMEL | Murata Electronics | FIXED IND 3.3UH 1.15A 100.8 MOHM | 3,987 | In Stock |  | 1 | 1 | Cut Tape (CT) | 490-15952-1-ND | 0.53000 | $0.53 | 1 |  | 490-15952-1-ND | 19 | https://search.murata.co.jp/Ceramy/image/img/P02/JELF243A-0153.pdf |  | N/A |  | Active | ROHS3 Compliant | 1 (Unlimited) | EAR99 | 8504.50.8000 | Japan |  | 490-15952-1-ND | https://mm.digikey.com/Volume0/opasdata/d220001/medias/images/408/LQH32C_53.jpg
29 | IN-S85ATG | Inolux | LED GREEN CLEAR 0805 SMD | 9,256 | In Stock |  | 11 | 11 | Cut Tape (CT) | 1830-1079-1-ND | 0.41500 | $4.56 | 1 |  | 1830-1079-1-ND | 5 | https://www.inolux-corp.com/datasheet/SMDLED/Mono%20Color%20Top%20View/IN-S85AT%20Series_V1.1.pdf |  | N/A |  | Active | ROHS3 Compliant | 3 (168 Hours) | EAR99 | 8541.41.0000 | China |  | 1830-1079-1-ND | https://mm.digikey.com/Volume0/opasdata/d220001/medias/images/918/IN-S85AT.JPG
30 | AIML-1206-R10K-T | Abracon LLC | FIXED IND 100NH 250MA 250MOHM SM | 2,072 | In Stock |  | 1 | 1 | Cut Tape (CT) | 535-11679-1-ND | 0.37000 | $0.37 | 1 |  | 535-11679-1-ND | 15 | https://abracon.com/Magnetics/chips/AIML-1206.pdf |  | May apply on shipments to the U.S. |  | Active | ROHS3 Compliant | 1 (Unlimited) | EAR99 | 8504.50.8000 | China | https://abracon.com/uploads/resources/REACH-224-SVHC-Certificate-Rev-S-2022-06-17-ABRACON-LLC.pdf | 535-11679-1-ND | https://mm.digikey.com/Volume0/opasdata/d220001/medias/images/659/AIML-1206.jpg
31 | GRM21BR71H474KA88L | Murata Electronics | CAP CER 0.47UF 50V X7R 0805 | 426 | In Stock |  | 2 | 2 | Cut Tape (CT) | 490-3328-1-ND | 0.32000 | $0.64 | 1 |  | 490-3328-1-ND | 19 | https://search.murata.co.jp/Ceramy/image/img/A01X/G101/ENG/GRM21BR71H474KA88-01.pdf |  | N/A |  | Active | ROHS3 Compliant | 1 (Unlimited) | EAR99 | 8532.24.0020 | Japan |  | 490-3328-1-ND | https://mm.digikey.com/Volume0/opasdata/d220001/medias/images/5447/490-Ceramic-Capacitor-Tan-Field.jpg
32 | C2012X5R0J336M125AC | TDK Corporation | CAP CER 33UF 6.3V X5R 0805 | 1,989 | In Stock |  | 2 | 2 | Cut Tape (CT) | 445-5986-1-ND | 1.06000 | $2.12 | 1 |  | 445-5986-1-ND | 24 | https://product.tdk.com/system/files/dam/doc/product/capacitor/ceramic/mlcc/catalog/mlcc_commercial_general_en.pdf |  | N/A |  | Active | ROHS3 Compliant | 1 (Unlimited) | EAR99 | 8532.24.0020 | Japan | https://product.tdk.com/system/files/dam/doc/product/capacitor/ceramic/mlcc/rohs/mlccrohs_commercial_general_en.pdf|https://product.tdk.com/en/environment/index.html | 445-5986-1-ND | https://mm.digikey.com/Volume0/opasdata/d220001/medias/images/4846/445_0805-(2012-Metric)-1,45mm-C-Series.jpg
33 | ERJ-6ENF1874V | Panasonic Electronic Components | RES SMD 1.87M OHM 1% 1/8W 0805 | 7,424 | In Stock |  | 1 | 1 | Cut Tape (CT) | P1.87BTCT-ND | 0.15000 | $0.15 | 1 |  | P1.87BTCT-ND | 21 | https://industrial.panasonic.com/cdbs/www-data/pdf/RDA0000/AOA0000C304.pdf |  | May apply on shipments to the U.S. |  | Active | ROHS3 Compliant | 1 (Unlimited) | EAR99 | 8533.21.0030 | China | https://industrial.panasonic.com/cdbs/www-cgi/auto-publishing.cgi?type=ROSU&region=WW&layer=4&cd=AOA0002 | P1.87BTCT-ND | https://mm.digikey.com/Volume0/opasdata/d220001/medias/images/2502/ERJ-0805 Pkg.jpg
34 | RC0805FR-07249KL | YAGEO | RES 249K OHM 1% 1/8W 0805 | 2,690 | In Stock |  | 1 | 1 | Cut Tape (CT) | 311-249KCRCT-ND | 0.15000 | $0.15 | 1 |  | 311-249KCRCT-ND | 18 | https://www.yageo.com/upload/media/product/productsearch/datasheet/rchip/PYu-RC_Group_51_RoHS_L_12.pdf |  | May apply on shipments to the U.S. |  | Active | ROHS3 Compliant | 1 (Unlimited) | EAR99 | 8533.21.0030 | China | https://www.yageo.com/en/Download/Index/certificates#rchip | 311-249KCRCT-ND | https://mm.digikey.com/Volume0/opasdata/d220001/medias/images/4848/13_0805-(2012-metric).jpg
35 | SM5817PL-TP | Micro Commercial Co | DIODE SCHOTTKY 20V 1A SOD123FL | 1,586 | In Stock |  | 2 | 2 | Cut Tape (CT) | SM5817PL-TPMSCT-ND | 0.43000 | $0.86 | 1 |  | SM5817PL-TPMSCT-ND | 11 | https://www.mccsemi.com/pdf/Products/SM5817PL-SM5819PL(SOD-123FL).PDF |  | May apply on shipments to the U.S. |  | Active | ROHS3 Compliant | 1 (Unlimited) | EAR99 | 8541.10.0080 | China | https://www.mccsemi.com/pdf/pbfree/Certification%20of%20Compliance%20of%20CaliforniaProposition65.pdf|https://www.mccsemi.com/pdf/pbfree/Certification%20of%20REACH%20Compliance.pdf|https://www.mccsemi.com/pdf/pbfree/Certification%20of%20RoHS%20Compliance.pdf | SM5817PL-TPMSCT-ND | https://mm.digikey.com/Volume0/opasdata/d220001/medias/images/5364/MFG_SMD22PL-TP.jpg
36 | ERA-6AEB131V | Panasonic Electronic Components | RES SMD 130 OHM 0.1% 1/8W 0805 | 2,325 | In Stock |  | 2 | 2 | Cut Tape (CT) | P130DACT-ND | 0.47000 | $0.94 | 1 |  | P130DACT-ND | 45 | https://industrial.panasonic.com/cdbs/www-data/pdf/RDM0000/AOA0000C307.pdf |  | N/A |  | Active | ROHS3 Compliant | 1 (Unlimited) | EAR99 | 8533.21.0030 | Japan | https://industrial.panasonic.com/cdbs/www-cgi/auto-publishing.cgi?type=ROSU&region=WW&layer=4&cd=AOA0026 | P130DACT-ND | https://mm.digikey.com/Volume0/opasdata/d220001/medias/images/2529/ERAS Series 0805 Pkg.jpg
37 | PJA3411_R1_00001 | Panjit International Inc. | SOT-23, MOSFET | 2,925 | In Stock |  | 2 | 2 | Cut Tape (CT) | 3757-PJA3411_R1_00001CT-ND | 0.67000 | $1.34 | 1 |  | 3757-PJA3411_R1_00001CT-ND | 18 | https://www.panjit.com.tw/upload/datasheet/PJA3411.pdf |  | N/A |  | Active | ROHS3 Compliant | 1 (Unlimited) | EAR99 | 8541.29.0095 | Taiwan |  | 3757-PJA3411_R1_00001CT-ND | https://mm.digikey.com/Volume0/opasdata/d220001/medias/images/2588/SOT-23-3 PKG.jpg
38 | IRFR5505TRPBF | Infineon Technologies | MOSFET P-CH 55V 18A DPAK | 2,022 | In Stock |  | 1 | 1 | Cut Tape (CT) | IRFR5505PBFCT-ND | 1.56000 | $1.56 | 1 |  | IRFR5505PBFCT-ND | 10 | https://www.infineon.com/dgdl/irfr5505pbf.pdf?fileId=5546d462533600a4015356358535210f |  | May apply on shipments to the U.S. |  | Active | ROHS3 Compliant | 1 (Unlimited) | EAR99 | 8541.29.0095 | United States | https://www.cypress.com/file/199231/download | IRFR5505PBFCT-ND | https://mm.digikey.com/Volume0/opasdata/d220001/medias/images/4845/448_TO252-3.jpg
39 | BC857BLT3G | onsemi | TRANS PNP 45V 0.1A SOT23-3 | 18,827 | In Stock |  | 2 | 2 | Cut Tape (CT) | BC857BLT3GOSCT-ND | 0.17000 | $0.34 | 1 |  | BC857BLT3GOSCT-ND | 12 | https://www.onsemi.com/pdf/datasheet/bc856alt1-d.pdf |  | May apply on shipments to the U.S. |  | Active | ROHS3 Compliant | 1 (Unlimited) | EAR99 | 8541.21.0075 | China | https://www.onsemi.com/PowerSolutions/MaterialComposition.do?export=pdf&opnId=BC857BLT3G|https://www.onsemi.com/site/pdf/REACH-compliance-statement.pdf|https://www.onsemi.com/site/pdf/RoHS-statement.pdf | BC857BLT3GOSCT-ND | https://mm.digikey.com/Volume0/opasdata/d220001/medias/images/4846/488_SOT-23-3,TO-236-3,Micro3,SSD3,SST3.jpg
40 | CSD17310Q5A | Texas Instruments | MOSFET N-CH 30V 21A/100A 8VSON | 1,628 | In Stock |  | 2 | 2 | Cut Tape (CT) | 296-25858-1-ND | 1.32000 | $2.64 | 1 |  | 296-25858-1-ND | 6 | https://www.ti.com/general/docs/suppproductinfo.tsp?distId=10 |  | May apply on shipments to the U.S. |  | Active | ROHS3 Compliant | 1 (Unlimited) | EAR99 | 8541.29.0095 | China |  | 296-25858-1-ND | https://mm.digikey.com/Volume0/opasdata/d220001/medias/images/2453/8-Power TDFN.jpg
41 | RC0805FR-071K3L | YAGEO | RES 1.3K OHM 1% 1/8W 0805 | 13,024 | In Stock |  | 1 | 1 | Cut Tape (CT) | 311-1.30KCRCT-ND | 0.15000 | $0.15 | 1 |  | 311-1.30KCRCT-ND | 18 | https://www.yageo.com/upload/media/product/app/datasheet/rchip/pyu-rc_group_51_rohs_l.pdf |  | May apply on shipments to the U.S. |  | Active | ROHS3 Compliant | 1 (Unlimited) | EAR99 | 8533.21.0030 | Taiwan | https://www.yageo.com/en/Download/Index/certificates#rchip | 311-1.30KCRCT-ND | https://mm.digikey.com/Volume0/opasdata/d220001/medias/images/4848/13_0805-(2012-metric).jpg
42 | CC0805DRNPO9BN6R0 | YAGEO | CAP CER 6PF 50V C0G/NPO 0805 | 1,010 | In Stock |  | 2 | 2 | Cut Tape (CT) | 311-1095-1-ND | 0.16000 | $0.32 | 1 |  | 311-1095-1-ND | 20 | https://www.yageo.com/upload/media/product/productsearch/datasheet/mlcc/UPY-GP_NP0_16V-to-50V_18.pdf |  | N/A |  | Active | ROHS3 Compliant | 1 (Unlimited) | EAR99 | 8532.24.0020 | Taiwan |  | 311-1095-1-ND | https://mm.digikey.com/Volume0/opasdata/d220001/medias/images/2485/0805(8^5mm thickness).jpg
43 | RMCF0805FT30R0 | Stackpole Electronics Inc | RES 30 OHM 1% 1/8W 0805 | 4,750 | In Stock |  | 1 | 1 | Cut Tape (CT) | RMCF0805FT30R0CT-ND | 0.15000 | $0.15 | 1 |  | RMCF0805FT30R0CT-ND | 15 | https://www.seielect.com/catalog/sei-rmcf_rmcp.pdf |  | May apply on shipments to the U.S. |  | Active | ROHS3 Compliant | 1 (Unlimited) | EAR99 | 8533.21.0030 | China | https://www.seielect.com/catalog/cert-of-compliance.pdf|https://www.seielect.com/catalog/reach.pdf|https://www.seielect.com/catalog/SEI-RoHS_Compliance_Status.pdf | RMCF0805FT30R0CT-ND | https://mm.digikey.com/Volume0/opasdata/d220001/medias/images/639/0805-RMCF-Series.jpg
44 | RC0805JR-070RL | YAGEO | RES 0 OHM JUMPER 1/8W 0805 | 2,029 | In Stock |  | 1 | 1 | Cut Tape (CT) | 311-0.0ARCT-ND | 0.15000 | $0.15 | 1 |  | 311-0.0ARCT-ND | 18 | https://www.yageo.com/upload/media/product/productsearch/datasheet/rchip/PYu-RC_Group_51_RoHS_L_12.pdf |  | May apply on shipments to the U.S. |  | Active | ROHS3 Compliant | 1 (Unlimited) | EAR99 | 8533.21.0030 | Taiwan | https://www.yageo.com/en/Download/Index/certificates#rchip | 311-0.0ARCT-ND | https://mm.digikey.com/Volume0/opasdata/d220001/medias/images/4848/13_0805-(2012-metric).jpg
45 | B3FS-1012P | Omron Electronics Inc-EMC Div | SWITCH TACTILE SPST-NO 0.05A 24V | 1,646 | In Stock |  | 1 | 1 | Cut Tape (CT) | SW1237CT-ND | 1.08000 | $1.08 | 1 |  | SW1237CT-ND | 14 | https://omronfs.omron.com/en_US/ecb/products/pdf/en-b3fs.pdf |  | May apply on shipments to the U.S. |  | Active | RoHS Compliant | 1 (Unlimited) | EAR99 | 8536.50.9031 | China |  | SW1237CT-ND | https://mm.digikey.com/Volume0/opasdata/d220001/medias/images/631/B3FS-1012P.JPG
46 | STM32F103CBT6 | STMicroelectronics | IC MCU 32BIT 128KB FLASH 48LQFP | 1,821 | In Stock |  | 1 | 1 | Tray | 497-6288-ND | 11.27000 | $11.27 | 1 |  | 497-6288-ND | 10 | https://www.st.com/resource/en/datasheet/stm32f103cb.pdf |  | N/A |  | Active | ROHS3 Compliant | 3 (168 Hours) | 3A991A2 | 8542.31.0001 | Malaysia |  | 497-6288-ND | https://mm.digikey.com/Volume0/opasdata/d220001/medias/images/389/48-LQFP.jpg
47 | L76L-M33 | Quectel | RF TXRX MOD NAVIGATION SMD | 1,091 | In Stock |  | 1 | 1 | Cut Tape (CT) | 2958-L76L-M33CT-ND | 17.41000 | $17.41 | 1 |  | 2958-L76L-M33CT-ND | 16 | https://www.quectel.com/wp-content/uploads/2021/03/Quectel_L76-L_GNSS_Specification_V1.4.pdf |  | May apply on shipments to the U.S. |  | Active | RoHS Compliant | 3 (168 Hours) | 5A992C SC | 8517.62.0090 | China |  | 2958-L76L-M33CT-ND | https://mm.digikey.com/Volume0/opasdata/d220001/medias/images/2923/MFG_L76L-M33.jpg
48 | ICM-20602 | TDK InvenSense | IMU ACCEL/GYRO/TEMP I2C/SPI LGA | 3,874 | In Stock |  | 1 | 1 | Cut Tape (CT) | 1428-1060-1-ND | 10.65000 | $10.65 | 1 |  | 1428-1060-1-ND | 52 | https://invensense.tdk.com/wp-content/uploads/2016/10/DS-000176-ICM-20602-v1.0.pdf?ref_disty=digikey |  | N/A |  | Not For New Designs | ROHS3 Compliant | 3 (168 Hours) | 7A994 | 8542.39.0001 | Taiwan |  | 1428-1060-1-ND | https://mm.digikey.com/Volume0/opasdata/d220001/medias/images/405/1428;16LGA-.80-3x3;;16.jpg
49 | USBLC6-2P6 | STMicroelectronics | TVS DIODE 5.25VWM 17VC SOT666 | 2,755 | In Stock |  | 1 | 1 | Cut Tape (CT) | 497-5026-1-ND | 0.89000 | $0.89 | 1 |  | 497-5026-1-ND | 29 | https://www.st.com/content/ccc/resource/technical/document/datasheet/06/1d/48/9c/6c/20/4a/b2/CD00050750.pdf/files/CD00050750.pdf/jcr:content/translations/en.C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 |  | May apply on shipments to the U.S. |  | Active | ROHS3 Compliant | 1 (Unlimited) | EAR99 | 8541.10.0080 | China |  | 497-5026-1-ND | https://mm.digikey.com/Volume0/opasdata/d220001/medias/images/4837/USBLC6-2P6.JPG
50 | MAX1898EUB42+T | Analog Devices Inc./Maxim Integrated | IC BATT CHG LI-ION 1CELL 10UMAX | 2,319 | In Stock |  | 1 | 1 | Cut Tape (CT) | MAX1898EUB42+TCT-ND | 7.73000 | $7.73 | 1 |  | MAX1898EUB42+TCT-ND | 21 | https://datasheets.maximintegrated.com/en/ds/MAX1898.pdf |  | N/A |  | Active | ROHS3 Compliant | 1 (Unlimited) | EAR99 | 8542.39.0001 | Thailand | https://www.maximintegrated.com/content/dam/files/design/emmi/reach-memo.pdf|https://www.maximintegrated.com/content/dam/files/design/emmi/rohs-certificate-of-compliance.pdf | MAX1898EUB42+TCT-ND | https://mm.digikey.com/Volume0/opasdata/d220001/medias/images/4810/175~21-0061~UB~10.JPG
51 | TPS61201DRCR | Texas Instruments | IC REG BOOST 3.3V 1.2A 10VSON | 1,399 | In Stock |  | 1 | 1 | Cut Tape (CT) | 296-44338-1-ND | 3.97000 | $3.97 | 1 |  | 296-44338-1-ND | 6 | https://www.ti.com/general/docs/suppproductinfo.tsp?distId=10 |  | N/A |  | Active | ROHS3 Compliant | 2 (1 Year) | EAR99 | 8542.39.0001 | Philippines |  | 296-44338-1-ND | https://mm.digikey.com/Volume0/opasdata/d220001/medias/images/3977/296~4204102-3~DRC~10.jpg
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

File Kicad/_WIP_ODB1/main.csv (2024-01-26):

# | Reference | Qty | Value | Footprint | DNP
1 | BATT_R1, BATT_R2, BATT_R3, BATT_R5, BATT_R6, BATT_R7 | 6 | 4K7
2 | BATT_R4, BATT_R8, BATT_R13 | 3 | 100K
3 | BATT_R9, BATT_R12, BATT_R14, R2 | 4 | 100k
4 | BATT_R10, BATT_R11 | 2 | 36k
5 | BMP_C1, BMP_C2, ICM_C3 | 3 | 10nf
6 | BMP_R1, GPS_R1, ICM_R1, SDC_R1 | 4 | 10k
7 | BMP_R2, GPS_R2, ICM_R3, SDC_R2, SDC_R3, SDC_R4, SDC_R5, SPI_R2, SPI_R3 | 9 | 10R
8 | BMP_R3, ICM_R2 | 2 | 10
9 | BT_C1, BT_C2, GPS_C2, GPS_C4, NRST_C1, USB_C3 | 6 | 100nf
10 | BT_R1, BT_R2 | 2 | 1K3
11 | BT_R3, R1 | 2 | 10K
12 | C1, PWR_C2, PWR_C4, PWR_C5, STM_C1, USB_C1 | 6 | 10uF
13 | C4, C5, PWR_C3, STM_C2, STM_C3, STM_C4, STM_C5 | 7 | 100nF
14 | D1, D2, D3, D4, D5, D6, D7, D8, D9, D10, D11, D12, D13, D14, D15, D20, D21, D22 | 18 | ESD5Zxx | Diode_SMD:D_SOD-523
15 | D16, D19 | 2 | GREEN
16 | D17, D18 | 2 | B260A-13-F
17 | E1 | 1 | HM-10 | HM-10:26.9X13X2.2_BOARD
18 | FB1, FB2, FB3 | 3 | 120R
19 | GPS_C1, GPS_C3, ICM_C2 | 3 | 10uf
20 | ICM_C1, ICM_C4 | 2 | 0.1uf
21 | J1, J13 | 2 | RFD900
22 | J2 | 1 | Micro_SD_Card
23 | J3 | 1 | USB_B_Micro
24 | J4 | 1 | SYS_SW
25 | J5 | 1 | Conn_Coaxial
26 | J6 | 1 | PYRO0
27 | J7 | 1 | PYRO1
28 | J8 | 1 | PYRO2
29 | J9 | 1 | PYRO3
30 | J10 | 1 | MAIN_BATT 12V
31 | J11 | 1 | BATT_LIPO
32 | J12 | 1 | BACKUP_BATT 12V
33 | JP1 | 1 | SolderJumper_2_Open
34 | JP2 | 1 | Jumper_2_Open
35 | L1 | 1 | 42nH
36 | LPWR_L1 | 1 | 3.3uH
37 | PWR_C1, PWR_C6, PWR_C8 | 3 | 22uF
38 | PWR_C7, PWR_C9, PYR_C1, PYR_C2, PYR_C3, PYR_C4, PYR_C5 | 7 | 100uf
39 | PWR_R2 | 1 | 1.85M
40 | PWR_R3 | 1 | 250k
41 | PYR_D1, PYR_D2, PYR_D3, PYR_D4 | 4 | D
42 | PYR_R1, PYR_R6, PYR_R13, PYR_R19 | 4 | 1k
43 | PYR_R2, PYR_R9, PYR_R15, PYR_R21 | 4 | 330
44 | PYR_R3, PYR_R5, PYR_R8, PYR_R10, PYR_R14, PYR_R16, PYR_R20, PYR_R22 | 8 | 4k7
45 | PYR_R4, PYR_R11, PYR_R17, PYR_R23 | 4 | 100
46 | PYR_R7, PYR_R12, PYR_R18, PYR_R24 | 4 | 47k
47 | Q1, Q2, Q11, Q14 | 4 | PMOS
48 | Q3, Q6, Q8, Q10 | 4 | NTF3055L108 | NTF3055L108:SOT223
49 | Q4, Q5, Q7, Q9 | 4 | PNP
50 | Q12, Q13 | 2 | PZT2222A | Package_TO_SOT_SMD:SOT-223-3_TabPin2
51 | R4 | 1 | 1k3
52 | STM_C6, USB_C2 | 2 | 1uF
53 | STM_C7, STM_C8 | 2 | 10nF
54 | U1 | 1 | STM32F103C8T6 | Package_QFP:LQFP-48_7x7mm_P0.5mm
55 | U2 | 1 | ICM-20602 | Package_LGA:LGA-16_3x3mm_P0.5mm_LayoutBorder3x5y
56 | U3 | 1 | BMP280 | Package_LGA:Bosch_LGA-8_2x2.5mm_P0.65mm_ClockwisePinNumbering
57 | U4 | 1 | L76L-M33 | L76L-M33:GNSS-MODULE_L76L-M33
58 | U5 | 1 | TPS61201DRCR | TPS61201DRCR:VREG_V62/16624-01YE
59 | U6 | 1 | max1898eub42+T | 21-0061L_MXM
60 | U7 | 1 | 74HC4051
61 | U8 | 1 | LM1085-5.0
62 | USB_R1 | 1 | 1K5

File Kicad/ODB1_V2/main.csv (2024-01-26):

Source: | C:\Users\Luka\Desktop\Ecole\Fusee\Inboard_main\main\main.kicad_sch
Date: | 10/8/2023 10:14:53 PM
Tool: | Eeschema 7.0.7
Generator: | F:\Logiciel\KiCad\7.0\bin\scripting\plugins/bom_csv_grouped_by_value_with_fp.py
Component Count: | 196
Ref | Qnty | Value | Cmp name | Footprint | Description | Vendor | DNP
5V_R1 | 1 | 1k | R | Resistor_SMD:R_0805_2012Metric | Resistor
5V_R2 | 1 | 56k | R | Resistor_SMD:R_0805_2012Metric | Resistor
5V_R3 | 1 | 100k | R | Resistor_SMD:R_0805_2012Metric | Resistor
BATT1S_R1 | 1 | 100k | R | Resistor_SMD:R_0805_2012Metric | Resistor
BATT1S_R2 | 1 | 27k | R | Resistor_SMD:R_0805_2012Metric | Resistor
BATT3S2_Q1, BATT3S2_Q2 | 2 | MMBT3904-TP | PZT2222A | Package_TO_SOT_SMD:SOT-23 | 1A Ic, 40V Vce, NPN Transistor, General Purpose Transistor, SOT-223
BATT3S2_R1 | 1 | 36k | R | Resistor_SMD:R_0805_2012Metric | Resistor
BATT3S2_R2, BATT3S2_R3 | 2 | 1k | R | Resistor_SMD:R_0805_2012Metric | Resistor
BATT3S2_R4 | 1 | 10K | R | Resistor_SMD:R_0805_2012Metric | Resistor
BATT3S2_R5 | 1 | 100k | R | Resistor_SMD:R_0805_2012Metric | Resistor
BATT3S2_R6, BATT3S2_R7, BATT3S2_R8 | 3 | 10k | R | Resistor_SMD:R_0805_2012Metric | Resistor
BATT3S2_R9 | 1 | 1K5 | R | Resistor_SMD:R_0805_2012Metric | Resistor
BATT3S_R1 | 1 | 36k | R | Resistor_SMD:R_0805_2012Metric | Resistor
BATT3S_R2 | 1 | 100k | R | Resistor_SMD:R_0805_2012Metric | Resistor
BMP_C1 | 1 | 10nf | C | Capacitor_SMD:C_0805_2012Metric | Unpolarized capacitor
BMP_R1, BMP_R3 | 2 | 10R | R | Resistor_SMD:R_0805_2012Metric | Resistor
BMP_R2 | 1 | 10k | R | Resistor_SMD:R_0805_2012Metric | Resistor
BT_C1 | 1 | 10uf | C | Capacitor_SMD:C_0805_2012Metric | Unpolarized capacitor
BT_C2 | 1 | 100nf | C | Capacitor_SMD:C_0805_2012Metric | Unpolarized capacitor
BT_R1 | 1 | 10K | R | Resistor_SMD:R_0805_2012Metric | Resistor
BT_R2, BT_R3 | 2 | 1K | R | Resistor_SMD:R_0805_2012Metric | Resistor
BUZ_R1 | 1 | 1k | R | Resistor_SMD:R_0805_2012Metric | Resistor
BUZ_R2 | 1 | 30R | R | Resistor_SMD:R_0805_2012Metric | Resistor
BZ1 | 1 | Buzzer | Buzzer | custom_footprints:GT-0930RP2 | Buzzer, polarized
C1, C2 | 2 | 100nf | C | Capacitor_SMD:C_0805_2012Metric | Unpolarized capacitor
C3 | 1 | 10uf | C | Capacitor_SMD:C_0805_2012Metric | Unpolarized capacitor
D1, D5 | 2 | B260A-13-F | D_Schottky | Diode_SMD:D_SMA | Schottky diode
D2, D4 | 2 | SP0503BAHTG | SP0503BAHT | Package_TO_SOT_SMD:SOT-143 | TVS Diode Array, 5.5V Standoff, 3 Channels, SOT-143 package
D3 | 1 | SP0504BAHTG | SP0504BAHT | Package_TO_SOT_SMD:SOT-23-5 | TVS Diode Array, 5.5V Standoff, 4 Channels, SOT-23-5 package
D6 | 1 | MMSZ4691-TP | BZV55C6V2 | Diode_SMD:D_SOD-123 | 6.2V, 500mW, 5%, Zener diode, MiniMELF
E1 | 1 | HM-10 | HM-10 | custom_footprints:26.9X13X2.2_BOARD
F1, F2 | 2 | 0ZCH0075AF2E (750ma) | Polyfuse_Small | Fuse:Fuse_1210_3225Metric | Resettable fuse, polymeric positive temperature coefficient, small symbol
F3 | 1 | 14A | Polyfuse_Small | Resistor_THT:R_Axial_DIN0207_L6.3mm_D2.5mm_P10.16mm_Horizontal | Resettable fuse, polymeric positive temperature coefficient, small symbol
FB1, FB2, FB3 | 3 | 120R | FerriteBead_Small | Inductor_SMD:L_0805_2012Metric | Ferrite bead, small symbol
GPS_C1, GPS_C3 | 2 | 100nf | C | Capacitor_SMD:C_0805_2012Metric | Unpolarized capacitor
GPS_C2, GPS_C4 | 2 | 10uf | C | Capacitor_SMD:C_0805_2012Metric | Unpolarized capacitor
GPS_R1 | 1 | 10k | R | Resistor_SMD:R_0805_2012Metric | Resistor
GPS_R2 | 1 | 10R | R | Resistor_SMD:R_0805_2012Metric | Resistor
H1, H2, H3, H4 | 4 | MountingHole | MountingHole | MountingHole:MountingHole_4mm | Mounting Hole without connection
ICM_C1, ICM_C4, ICM_C5 | 3 | 100nf | C | Capacitor_SMD:C_0805_2012Metric | Unpolarized capacitor
ICM_C2, ICM_C7 | 2 | 10uf | C | Capacitor_SMD:C_0805_2012Metric | Unpolarized capacitor
ICM_C3 | 1 | 10nf | C | Capacitor_SMD:C_0805_2012Metric | Unpolarized capacitor
ICM_C6 | 1 | 1uf | C | Capacitor_SMD:C_0805_2012Metric | Unpolarized capacitor
ICM_R1, ICM_R3 | 2 | 10R | R | Resistor_SMD:R_0805_2012Metric | Resistor
ICM_R2 | 1 | 10k | R | Resistor_SMD:R_0805_2012Metric | Resistor
J1 | 1 | RF2-04A-T-00-50-G | Conn_Coaxial | Connector_Coaxial:SMA_Wurth_60312002114503_Vertical | coaxial connector (BNC, SMA, SMB, SMC, Cinch/RCA, LEMO, ...)
J2 | 1 | RFD900 | Conn_01x04_Pin | custom_footprints:B4B-PH-K | Generic connector, single row, 01x04, script generated
J3 | 1 | Conn_02x05_Odd_Even | Conn_02x05_Odd_Even | Connector_PinHeader_1.27mm:PinHeader_2x05_P1.27mm_Vertical | Generic connector, double row, 02x05, odd/even pin numbering scheme (row 1 odd numbers, row 2 even numbers), script generated (kicad-library-utils/schlib/autogen/connector/)
J4 | 1 | CAM | Conn_01x04_Pin | custom_footprints:B4B-PH-K | Generic connector, single row, 01x04, script generated
J5 | 1 | MEM2067-02-180-00-A_REVB | MEM2067-02-180-00-A_REVB | custom_footprints:GCT_MEM2067-02-180-00-A_REVB
J6 | 1 | USB_B_Micro | USB_B_Micro | Connector_USB:USB_Micro-B_Molex-105017-0001 | USB Micro Type B connector
J7 | 1 | EXT_STATUS_LED | Screw_Terminal_01x02 | custom_footprints:B2B-PH-K | Generic screw terminal, single row, 01x02, script generated (kicad-library-utils/schlib/autogen/connector/)
J8 | 1 | BATT1S | Screw_Terminal_01x02 | Connector_Wire:SolderWire-2.5sqmm_1x02_P8.8mm_D2.4mm_OD4.4mm | Generic screw terminal, single row, 01x02, script generated (kicad-library-utils/schlib/autogen/connector/)
J9 | 1 | BATT3S1 | Screw_Terminal_01x02 | Connector_Wire:SolderWire-2.5sqmm_1x02_P8.8mm_D2.4mm_OD4.4mm | Generic screw terminal, single row, 01x02, script generated (kicad-library-utils/schlib/autogen/connector/)
J10 | 1 | EXT_SW | Screw_Terminal_01x02 | custom_footprints:B2B-PH-K | Generic screw terminal, single row, 01x02, script generated (kicad-library-utils/schlib/autogen/connector/)
J11 | 1 | BATT3S2 | Screw_Terminal_01x02 | Connector_Wire:SolderWire-2.5sqmm_1x02_P8.8mm_D2.4mm_OD4.4mm | Generic screw terminal, single row, 01x02, script generated (kicad-library-utils/schlib/autogen/connector/)
J12 | 1 | PYRO0 | Screw_Terminal_01x02 | TerminalBlock_RND:TerminalBlock_RND_205-00012_1x02_P5.00mm_Horizontal | Generic screw terminal, single row, 01x02, script generated (kicad-library-utils/schlib/autogen/connector/)
J13 | 1 | PYRO1 | Screw_Terminal_01x02 | TerminalBlock_RND:TerminalBlock_RND_205-00012_1x02_P5.00mm_Horizontal | Generic screw terminal, single row, 01x02, script generated (kicad-library-utils/schlib/autogen/connector/)
JP1, JP2, JP4, JP5 | 4 | SolderJumper_2_Open | SolderJumper_2_Open | Jumper:SolderJumper-2_P1.3mm_Open_TrianglePad1.0x1.5mm | Solder Jumper, 2-pole, open
JP3 | 1 | SolderJumper_2_Bridged | SolderJumper_2_Bridged | Jumper:SolderJumper-2_P1.3mm_Bridged2Bar_RoundedPad1.0x1.5mm | Solder Jumper, 2-pole, closed/bridged
L1 | 1 | 100nH | L | Inductor_SMD:L_0805_2012Metric | Inductor
LED_3S2_ON1 | 1 | GREEN | LED | LED_SMD:LED_0805_2012Metric | Light emitting diode
LED_3V1 | 1 | GREEN | LED | LED_SMD:LED_0805_2012Metric | Light emitting diode
LED_5V1 | 1 | GREEN | LED | LED_SMD:LED_0805_2012Metric | Light emitting diode
LED_14V1 | 1 | GREEN | LED | LED_SMD:LED_0805_2012Metric | Light emitting diode
LED_BT1 | 1 | GREEN | LED | LED_SMD:LED_0805_2012Metric | Light emitting diode
LED_CHG1 | 1 | GREEN | LED | LED_SMD:LED_0805_2012Metric | Light emitting diode
LED_PYRO_0.1 | 1 | GREEN | LED | LED_SMD:LED_0805_2012Metric | Light emitting diode
LED_PYRO_1, LED_PYRO_2 | 2 | GREEN | LED | LED_SMD:LED_0805_2012Metric | Light emitting diode
LED_PYRO_1.1 | 1 | GREEN | LED | LED_SMD:LED_0805_2012Metric | Light emitting diode
LED_R1 | 1 | 1k | R | Resistor_SMD:R_0805_2012Metric | Resistor
LED_STATUS1 | 1 | GREEN | LED | LED_SMD:LED_0805_2012Metric | Light emitting diode
LPWR_L1 | 1 | 3.3uH | L | custom_footprints:IND_LQH3NPN3R3MMEL | Inductor
LTC_C1, LTC_C3 | 2 | 100nF | C | Capacitor_SMD:C_0805_2012Metric | Unpolarized capacitor
LTC_C2, LTC_C4 | 2 | 0.47uf | C | Capacitor_SMD:C_0805_2012Metric | Unpolarized capacitor
LTC_R1, LTC_R2, LTC_R3 | 3 | 100K | R | Resistor_SMD:R_0805_2012Metric | Resistor
NRST_C1 | 1 | 100nf | C | Capacitor_SMD:C_0805_2012Metric | Unpolarized capacitor
PWR_C1, PWR_C5, PWR_C7 | 3 | 10uf | C | Capacitor_SMD:C_0805_2012Metric | Unpolarized capacitor
PWR_C2, PWR_C4, PWR_C6, PWR_C8 | 4 | 100nf | C | Capacitor_SMD:C_0805_2012Metric | Unpolarized capacitor
PWR_C3 | 1 | 33uf | C | Capacitor_SMD:C_0805_2012Metric | Unpolarized capacitor
PWR_C9 | 1 | 10uf | C | Capacitor_SMD:C_1206_3216Metric | Unpolarized capacitor
PWR_C10 | 1 | 33uf | C | Capacitor_SMD:C_1206_3216Metric | Unpolarized capacitor
PWR_C11 | 1 | 100nf | C | Capacitor_SMD:C_1206_3216Metric | Unpolarized capacitor
PWR_R1 | 1 | 1.85M | R | Resistor_SMD:R_0805_2012Metric | Resistor
PWR_R2 | 1 | 250k | R | Resistor_SMD:R_0805_2012Metric | Resistor
PWR_R3 | 1 | 1k | R | Resistor_SMD:R_0805_2012Metric | Resistor
PYR_C1, PYR_C2, PYR_C3, PYR_C4, PYR_C5, PYR_C6 | 6 | 100nf | C | Capacitor_SMD:C_0805_2012Metric | Unpolarized capacitor
PYR_D1, PYR_D2 | 2 | SM5817PL-TP | D | Diode_SMD:D_1206_3216Metric | Diode
PYR_R1, PYR_R4, PYR_R11, PYR_R13 | 4 | 1k | R | Resistor_SMD:R_0805_2012Metric | Resistor
PYR_R2, PYR_R3, PYR_R10, PYR_R12 | 4 | 1K | R | Resistor_SMD:R_0805_2012Metric | Resistor
PYR_R5, PYR_R6, PYR_R7, PYR_R14, PYR_R15, PYR_R16 | 6 | 10k | R | Resistor_SMD:R_0805_2012Metric | Resistor
PYR_R8, PYR_R17 | 2 | 130R 1% | R | Resistor_SMD:R_0805_2012Metric | Resistor
PYR_R9, PYR_R18 | 2 | 56k | R | Resistor_SMD:R_0805_2012Metric | Resistor
PYRO_Q1, PYRO_Q2 | 2 | MMBT3904-TP | PZT2222A | Package_TO_SOT_SMD:SOT-23 | 1A Ic, 40V Vce, NPN Transistor, General Purpose Transistor, SOT-223
Q1, Q2 | 2 | PMOS | PMOS | Package_TO_SOT_SMD:SOT-23-3 | P-MOSFET transistor, drain/source/gate
Q3 | 1 | IRFR5505TRPBF | IRFR5505TRPBF | custom_footprints:PG-TO252AA_INF
Q4, Q6 | 2 | BC857 | BC857 | Package_TO_SOT_SMD:SOT-23 | 0.1A Ic, 45V Vce, PNP Transistor, SOT-23
Q5, Q7 | 2 | CSD17310Q5A | CSD17310Q5A | Package_TO_SOT_SMD:TDSON-8-1 | 100A Id, 30V Vds, NexFET N-Channel Power MOSFET, 5.9mOhm Ron, Qg (typ) 8.9nC, SON8 5x6mm
R1 | 1 | 1k3 | R | Resistor_SMD:R_0805_2012Metric | Resistor
R2 | 1 | 100k | R | Resistor_SMD:R_0805_2012Metric | Resistor
RDX_D1 | 1 | B260A-13-F | D_Schottky | Diode_SMD:D_SOD-123F | Schottky diode
RSTM_R1 | 1 | 1k | R | Resistor_SMD:R_0805_2012Metric | Resistor
SDC_R1, SDC_R2, SDC_R3, SDC_R4 | 4 | 10R | R | Resistor_SMD:R_0805_2012Metric | Resistor
SDC_R5 | 1 | 10k | R | Resistor_SMD:R_0805_2012Metric | Resistor
SDC_R6 | 1 | 1k | R | Resistor_SMD:R_0805_2012Metric | Resistor
SPI_R1, SPI_R2 | 2 | 10R | R | Resistor_SMD:R_0805_2012Metric | Resistor
STM_C1, STM_C2 | 2 | 10uf | C | Capacitor_SMD:C_0805_2012Metric | Unpolarized capacitor
STM_C3, STM_C9 | 2 | 6p | C | Capacitor_SMD:C_0805_2012Metric | Unpolarized capacitor
STM_C4, STM_C6, STM_C8, STM_C10 | 4 | 100nf | C | Capacitor_SMD:C_0805_2012Metric | Unpolarized capacitor
STM_C5, STM_C7 | 2 | 10nf | C | Capacitor_SMD:C_0805_2012Metric | Unpolarized capacitor
STM_R1, STM_R3 | 2 | 10K | R | Resistor_SMD:R_0805_2012Metric | Resistor
STM_R2 | 1 | 30 | R | Resistor_SMD:R_0805_2012Metric | Resistor
SW1 | 1 | POWER BUTTON | SW_Omron_B3FS | Button_Switch_SMD:SW_SPST_Omron_B3FS-105xP | Omron B3FS 6x6mm single pole normally-open tactile switch
U1 | 1 | STM32F103CBT6 | STM32F103C8Tx | Package_QFP:LQFP-48_7x7mm_P0.5mm | STMicroelectronics Arm Cortex-M3 MCU, 64KB flash, 20KB RAM, 72 MHz, 2.0-3.6V, 37 GPIO, LQFP48
U2 | 1 | L76L-M33 | L76L-M33 | custom_footprints:GNSS-MODULE_L76L-M33
U3 | 1 | ICM-20602 | ICM-20602 | Package_LGA:LGA-16_3x3mm_P0.5mm_LayoutBorder3x5y | High performance 6-Axis MEMS motion tracking, SPI/I2C interface, LGA-16
U4 | 1 | BMP280 | BMP280 | Package_LGA:Bosch_LGA-8_2x2.5mm_P0.65mm_ClockwisePinNumbering | Absolute Barometric Pressure Sensor, LGA-8
U5 | 1 | USBLC6-2P6 | USBLC6-2P6 | Package_TO_SOT_SMD:SOT-666 | Very low capacitance ESD protection diode, 2 data-line, SOT-666
U6 | 1 | max1898eub42+T | max1898eub42+T | custom_footprints:21-0061L_MXM
U7 | 1 | TPS61201DRCR | TPS61201DRCR | Package_SON:VSON-10-1EP_3x3mm_P0.5mm_EP1.65x2.4mm
U8 | 1 | LM1085-5.0 | LM1085-5.0 | Package_TO_SOT_SMD:TO-263-3_TabPin2 | 3A 25V Linear Regulator, Fixed Output 5.0V, TO-220/TO-263
U9 | 1 | LTC2954ITS8-1 | LTC2954ITS8-1#TRPBF | Package_TO_SOT_SMD:TSOT-23-8
U10 | 1 | 74HC2G86DP_125 | 74HC2G86DP_125_1 | Package_SO:TSSOP-8_4.4x3mm_P0.65mm
U11 | 1 | 74HC2G08DP,125 | 74HC2G86DP_125 | Package_SO:TSSOP-8_4.4x3mm_P0.65mm
U12 | 1 | 74HC4051 | 74HC4051 | Package_SO:SSOP-16_5.3x6.2mm_P0.65mm | 8-channel analog multiplexer/demultiplexer, DIP-16/SOIC-16/TSSOP-16
U13 | 1 | 74LVC2G02DP,125 | 74HC2G86DP_125 | Package_SO:TSSOP-8_4.4x3mm_P0.65mm
USB_R1 | 1 | 1K5 | R | Resistor_SMD:R_0805_2012Metric | Resistor
Y1 | 1 | 16mhz | Crystal_GND24 | Crystal:Crystal_SMD_3225-4Pin_3.2x2.5mm | Four pin crystal, GND on pins 2 and 4

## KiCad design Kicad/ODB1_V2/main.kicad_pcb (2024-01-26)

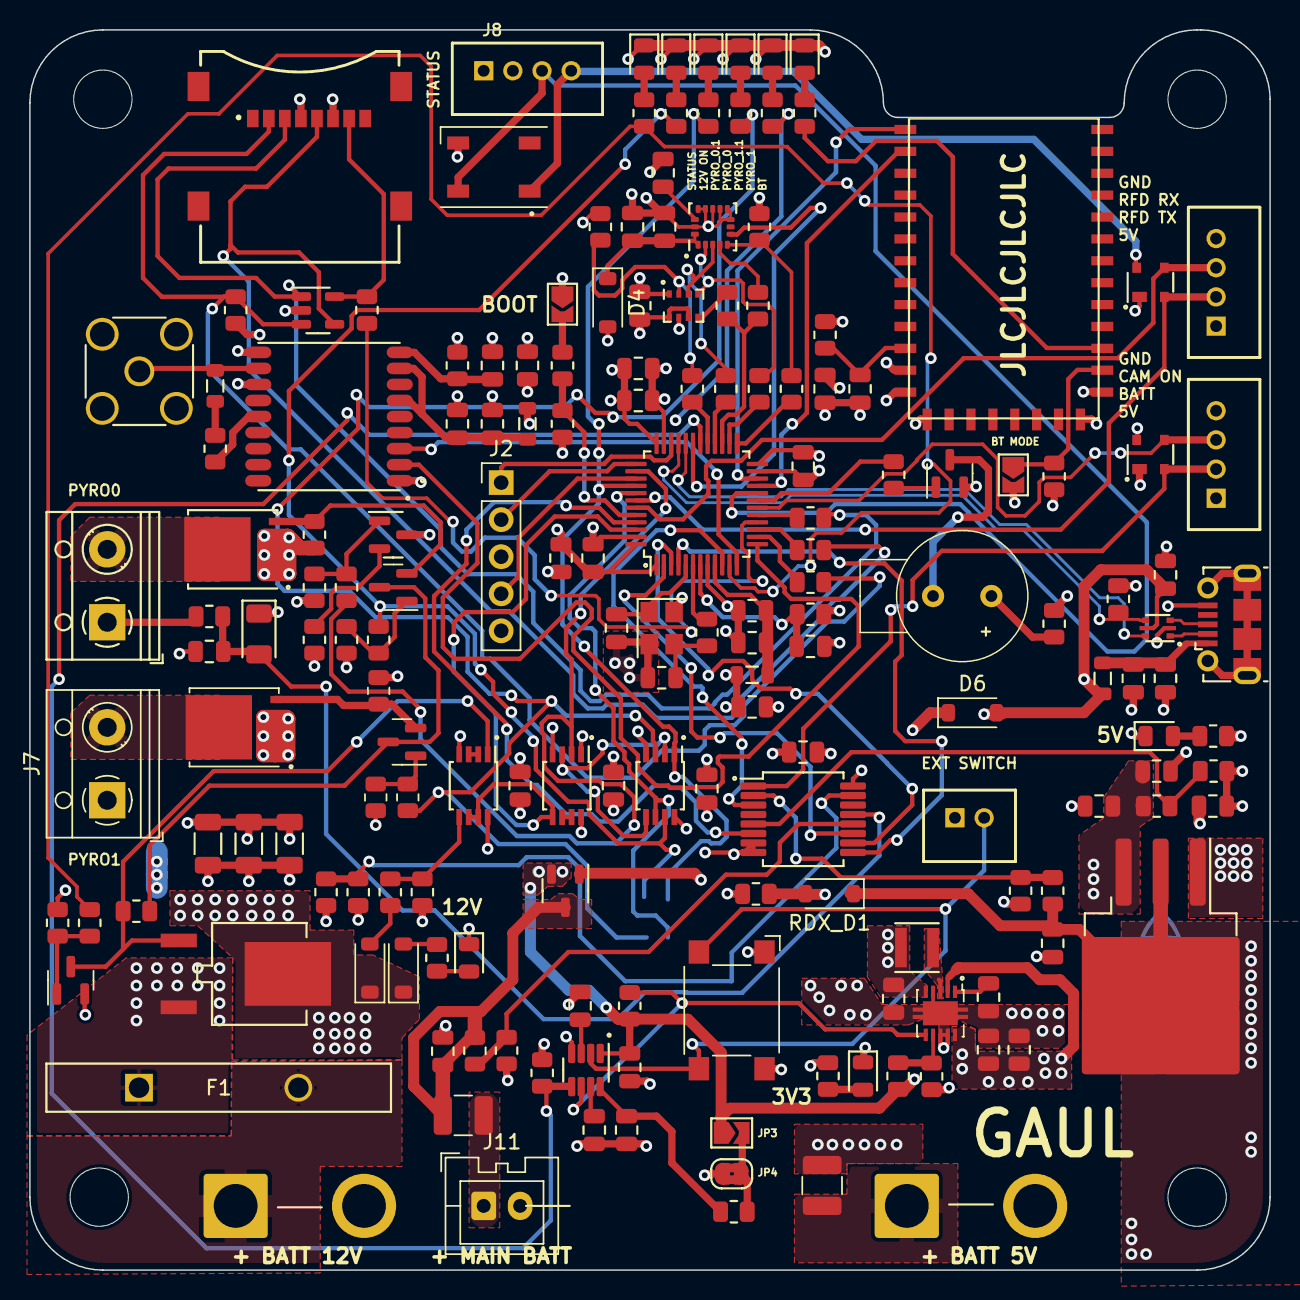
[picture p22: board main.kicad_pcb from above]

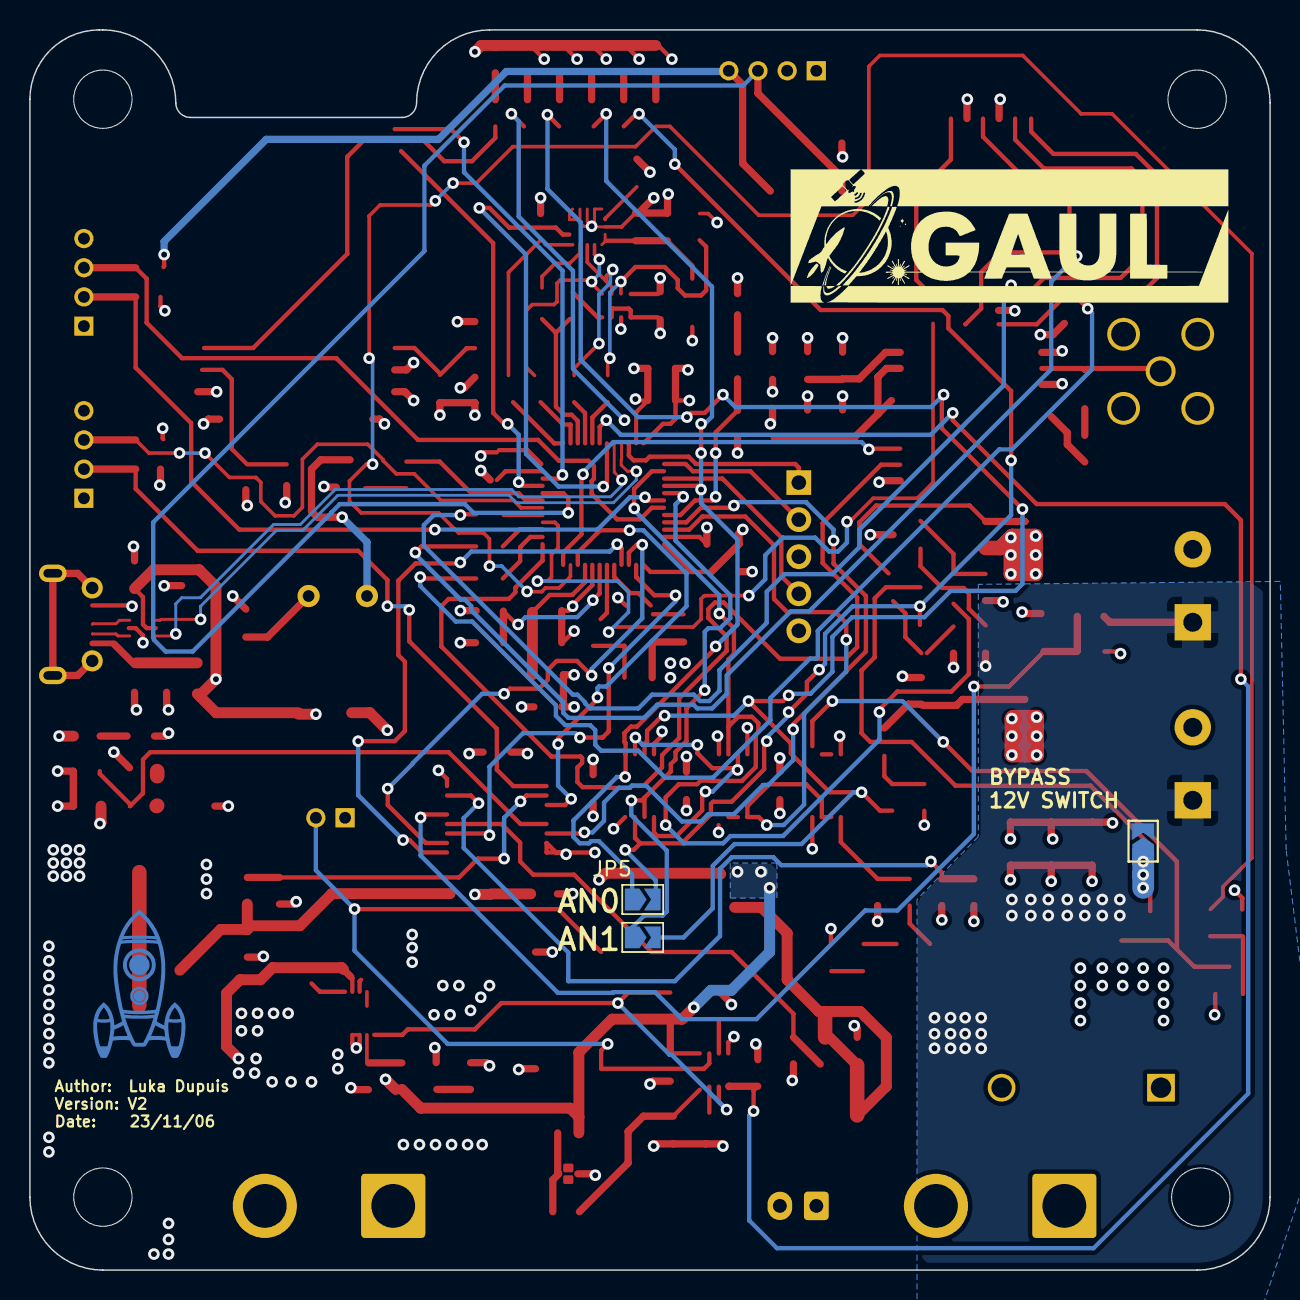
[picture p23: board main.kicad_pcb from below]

Board: 4 copper layers, 85.0 x 85.0 mm, 183 parts (3 on the bottom side), 122 nets.

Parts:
5V_R1: 56k; R_0805_2012Metric
5V_R2: 100k; R_0805_2012Metric
5V_R3: 1k5; R_0805_2012Metric
BATT1S_R13, BATT3S2_R12, BATT3S_R9: 100k; R_0805_2012Metric
BATT1S_R14: 27k; R_0805_2012Metric
BATT3S2_Q2: MMBT3904-TP; SOT-23
BATT3S2_R1, BATT3S2_R3, BATT3S2_R4, BATT3S2_R5: 10k; R_0805_2012Metric
BATT3S2_R2, BATT3S2_R6, BATT3S2_R7: 1k5; R_0805_2012Metric
BATT3S2_R11, BATT3S_R8: 36k; R_0805_2012Metric
BMP_C1: 10nf; C_0805_2012Metric
BMP_R1: 10k; R_0805_2012Metric
BMP_R2, BMP_R3: 10R; R_0805_2012Metric
BT_C1: 100nf; C_0805_2012Metric
BT_C2: 10uf; C_0805_2012Metric
BT_R1, BT_R2: 1k5; R_0805_2012Metric
BT_R3: 10k; R_0805_2012Metric
BUZ_R1: 1k5; R_0805_2012Metric
BUZ_R2: 30R; R_0805_2012Metric
BZ1: Buzzer; GT-0930RP2
C1: 10uf; C_0805_2012Metric
D1, D2: SP0503BAHTG; SOT-143
D3, D16: MMSZ4691-TP; D_SOD-123
D4, D6: B260A-13-F; D_SOD-123
D5: WS2812B; LED_WS2812B_PLCC4_5.0x5.0mm_P3.2mm
D8: SP0504BAHTG; SOT-23-5
E1: HM-10; 26.9X13X2.2_BOARD
F1: RGEF1400; FUS_RGEF1400_TYCO_TYC
F2, F3: 0ZCH0075AF2E (750ma); Fuse_1210_3225Metric
FB1, FB2, FB3: 120R; L_0805_2012Metric
GPS_C1, GPS_C3: 10uf; C_0805_2012Metric
GPS_C2, GPS_C4: 100nf; C_0805_2012Metric
GPS_R1: 10k; R_0805_2012Metric
GPS_R2: 10R; R_0805_2012Metric
H1, H2, H3, H4: MountingHole; MountingHole_4mm
ICM_C1, ICM_C4, ICM_C5: 100nf; C_0805_2012Metric
ICM_C2, ICM_C7: 10uf; C_0805_2012Metric
ICM_C6: 1uf; C_0805_2012Metric
ICM_R1: 10k; R_0805_2012Metric
ICM_R2, ICM_R3: 10R; R_0805_2012Metric
J1: RFD900; B4B-PH-K
J2: Conn_01x05_Socket; PinHeader_1x05_P2.54mm_Vertical
J3: USB_B_Micro; USB_Micro-B_Molex-105017-0001
J4: MEM2067-02-180-00-A_REVB; GCT_MEM2067-02-180-00-A_REVB
J5: RF2-04A-T-00-50-G; SMA_Wurth_60312002114503_Vertical
J6: PYRO0; TerminalBlock_RND_205-00012_1x02_P5.00mm_Horizontal
J7: PYRO1; TerminalBlock_RND_205-00012_1x02_P5.00mm_Horizontal
J8, J13: CAM; B4B-PH-K
J9: BATT3S1; SolderWire-2.5sqmm_1x02_P8.8mm_D2.4mm_OD4.4mm
J10: BATT12V; SolderWire-2.5sqmm_1x02_P8.8mm_D2.4mm_OD4.4mm
J11: BATT1S; JST_XA_B02B-XASK-1_1x02_P2.50mm_Vertical
J12: EXT_SW; B2B-PH-K
JP1, JP2, JP3, JP5, JP6, JP7: SolderJumper_2_Open; SolderJumper-2_P1.3mm_Open_TrianglePad1.0x1.5mm
JP4: SolderJumper_2_Bridged; SolderJumper-2_P1.3mm_Bridged2Bar_RoundedPad1.0x1.5mm
L1: 100nH; L_0805_2012Metric
LED_3S2_ON1, LED_3V3, LED_5V1, LED_14V8: GREEN; LED_0805_2012Metric
LED_BT1: GREEN; LED_0805_2012Metric
LED_PYRO_0, LED_PYRO_0.1, LED_PYRO_1, LED_PYRO_1.1: GREEN; LED_0805_2012Metric
LPWR_L1: 3.3uH; IND_LQH3NPN3R3MMEL
LTC_C1, LTC_C2: 100nf; C_0805_2012Metric
LTC_C3, LTC_C4: 0.47uf; C_0805_2012Metric
LTC_R1, LTC_R2, LTC_R3: 10k; R_0805_2012Metric
NRST_C1: 100nf; C_0805_2012Metric
PWR_C1: 33uf; C_0805_2012Metric
PWR_C2, PWR_C4, PWR_C5: 10uf; C_0805_2012Metric
PWR_C3, PWR_C8, PWR_C9, PWR_C11: 100nf; C_0805_2012Metric
PWR_C6: 10uf; C_1206_3216Metric
PWR_C7: 100nf; C_1206_3216Metric
PWR_C10: 33uf; C_1206_3216Metric
PWR_R1: 1k5; R_0805_2012Metric
PWR_R2: 1.87M; R_0805_2012Metric
PWR_R3: 249k; R_0805_2012Metric
PYRO_Q3, PYRO_Q211: MMBT3904-TP; SOT-23
PYR_C1, PYR_C3, PYR_C4, PYR_C5, PYR_C6: 100nf; C_0805_2012Metric
PYR_D1: SM5817PL-TP; D_1206_3216Metric
PYR_R2, PYR_R6, PYR_R9, PYR_R13, PYR_R14, PYR_R15, PYR_R16: 1k5; R_0805_2012Metric
PYR_R3, PYR_R5, PYR_R17, PYR_R18, PYR_R19: 10k; R_0805_2012Metric
PYR_R4: 130R 1%; R_0805_2012Metric
PYR_R7: 56k; R_0805_2012Metric
Q2: PMOS; SOT-23-3
Q3, Q8: CSD17310Q5A; TDSON-8-1
Q4: MMBT3904; SOT-23
Q5: IRFR5505TRPBF; PG-TO252AA_INF
Q6: BC857; SOT-23
R2: 100k; R_0805_2012Metric
RDX_D1: B260A-13-F; D_SOD-123
RSTM_R2: 1k5; R_0805_2012Metric
SDC_R1: 10k; R_0805_2012Metric
SDC_R2, SDC_R3, SDC_R4, SDC_R5: 10R; R_0805_2012Metric
SPI_R2, SPI_R3: 10R; R_0805_2012Metric
STM_C1, STM_C6: 10uf; C_0805_2012Metric
STM_C2, STM_C3, STM_C4, STM_C5: 100nf; C_0805_2012Metric
STM_C7, STM_C8: 10nf; C_0805_2012Metric
STM_C9, STM_C10: 6p; C_0805_2012Metric
STM_R1, STM_R3: 10k; R_0805_2012Metric
STM_R4: 30R; R_0805_2012Metric
SW1: POWER BUTTON; SW_SPST_Omron_B3FS-105xP
U1: STM32F103CBT6; LQFP-48_7x7mm_P0.5mm
U2: ICM-20602; LGA-16_3x3mm_P0.5mm_LayoutBorder3x5y
U3: BMP280; Bosch_LGA-8_2x2.5mm_P0.65mm_ClockwisePinNumbering
U4: L76L-M33; GNSS-MODULE_L76L-M33
U5: TPS61201DRCR; VSON-10-1EP_3x3mm_P0.5mm_EP1.65x2.4mm
U7: 74HC4051; SSOP-16_5.3x6.2mm_P0.65mm
U8: LM1085-5.0; TO-263-3_TabPin2
U9: 74HC2G08DP,125; TSSOP-8_3x3mm_P0.65mm
U10: 74LVC2G02DP,125; TSSOP-8_3x3mm_P0.65mm
U11: LTC2954ITS8-1; TSOT-23-8
U12: USBLC6-2P6; SOT-666
U13: 74HC2G86DP_125; TSSOP-8_3x3mm_P0.65mm
USB_R1: 1k5; R_0805_2012Metric
Y1: 16mhz; Crystal_SMD_3225-4Pin_3.2x2.5mm

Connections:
3V3_EN: LTC_R1.1, U5.6 (EN), U11.6 (EN)
5V_AN: 5V_R1.2, 5V_R2.2, U7.2 (A6)
12V_CHECK: U1.46 (PB9), U10.6 (2B), U10.7 (1Y), U13.5 (2A)
+3.3VA: FB3.1, STM_C6.2, STM_C7.2, U1.9 (VDDA)
+3V3: BMP_C1.1, BMP_R1.1, BT_C2.1, BT_R2.2, BT_R3.1, BUZ_R2.1, D4.2 (A), E1.12 (+3.3V), FB1.2, FB3.2, GPS_C3.2, GPS_R1.2, ICM_R1.1, J2.3, J4.4 (VDD), JP1.1 (A), JP4.1 (A), LTC_R3.1, PWR_C1.1, PWR_C8.1, PWR_R1.1, PYR_C3.1, PYR_C4.1, PYR_C5.2, PYR_C6.1, PYR_D1.1 (K), PYR_R5.1, Q6.3 (C), SDC_R1.2, STM_C1.2, STM_C2.2, STM_C3.2, STM_C4.2, STM_C5.2, STM_C8.2, STM_R1.2, U1.1 (VBAT), U1.24 (VDD), U1.36 (VDD), U1.48 (VDD), U3.6 (VDDIO), U3.8 (VDD), U5.2 (VOUT), U5.10 (FB), U7.16 (VCC), U9.8 (VCC), U10.8 (VCC), U13.1 (1A), U13.8 (VCC), USB_R1.2
+5V: 5V_R1.1, 5V_R3.1, D1.4 (K), D2.4 (K), D5.1 (VDD), J1.1, J8.4, J13.1, PWR_C5.1, PWR_C11.1, RDX_D1.1 (K), U8.2 (VO)
+12C: BATT3S2_R1.1, BATT3S2_R12.2, F1.1, JP6.1 (A), PWR_C6.1, PWR_C7.1, PWR_C10.1, PYRO_Q3.3 (C), PYRO_Q211.3 (C), Q5.3 (S)
+12P: BATT3S_R9.2, F3.1, PWR_C4.1, PWR_C9.1, U8.3 (VI)
+12V: D3.1 (K), D16.1 (K), J6.1, J7.1, JP6.2 (B), PYR_R4.1, PYR_R7.1, Q5.2 (D)
+BATT: BATT1S_R14.2, C1.1, F2.1, Q2.3 (D)
/Power/12IN: F1.2, J10.1
BATT3S2_ON: BATT3S2_R2.1, BATT3S2_R7.1, U1.11 (PA1)
BATT_CAM: D2.2 (K), J13.2, U7.1 (A4)
BATT_LIPO1S_AN: BATT1S_R13.2, BATT1S_R14.1, U7.12 (A3)
BATT_LIPO3S2_AN: BATT3S2_R11.2, BATT3S2_R12.1, U7.15 (A2)
BATT_LIPO3S_AN: BATT3S_R8.2, BATT3S_R9.1, U7.5 (A5)
BMP_CS: BMP_R1.2, BMP_R2.2, U3.2 (CSB)
BOOT0: RSTM_R2.1, STM_R3.2, U1.44 (BOOT0)
BT_RX: E1.1 (UART_TX), U1.22 (PB11)
BT_TX: E1.2 (UART_RX), U1.21 (PB10)
BUTTON_INT: LTC_R3.2, U1.30 (PA9), U11.5 (*INT)
BUZZER: BUZ_R1.1, U1.19 (PB1)
CAM_ON: D2.3 (K), J13.3, U1.18 (PB0)
FLIP_FLOP_RST: BATT3S2_R1.2, Q4.3 (C), Q5.1 (G), U10.1 (1A)
FLIP_FLOP_SET: BATT3S2_R4.1, BATT3S2_R5.1, U10.5 (2A)
GND: 5V_R2.1, BATT1S_R13.1, BATT3S2_Q2.2 (E), BATT3S2_R3.1, BATT3S2_R5.2, BATT3S2_R11.1, BATT3S_R8.1, BMP_C1.2, BT_C1.2, BT_C2.2, C1.2, D1.1 (A), D2.1 (A), D5.3 (VSS), D8.2 (A), E1.13 (GND), E1.14 (GND), E1.21 (GND), E1.22 (GND), GPS_C1.1, GPS_C2.1, GPS_C3.1, GPS_C4.1, ICM_C1.1, ICM_C2.1, ICM_C4.2, ICM_C5.1, ICM_C6.1, ICM_C7.1, J1.4, J2.5, J3.5 (GND), J4.6 (VSS), J5.2 (Ext), J8.2, J9.2, J10.2, J11.2, J12.1, J13.4, JP2.2 (B), LED_3S2_ON1.1 (K), LED_3V3.1 (K), LED_5V1.1 (K), LED_14V8.1 (K), LED_BT1.1 (K), LED_PYRO_0.1 (K), LED_PYRO_0.1.1 (K), LED_PYRO_1.1 (K), LED_PYRO_1.1.1 (K), LTC_C1.2, LTC_C2.2, LTC_C3.2, LTC_C4.2, NRST_C1.2, PWR_C1.2, PWR_C2.2, PWR_C3.2, PWR_C4.2, PWR_C5.2, PWR_C6.2, PWR_C7.2, PWR_C8.2, PWR_C9.2, PWR_C10.2, PWR_C11.2, PWR_R3.2, PYR_C1.2, PYR_C3.2, PYR_C4.2, PYR_C5.1, PYR_C6.2, PYR_R3.1, PYR_R17.1, PYR_R18.1, PYR_R19.1, Q3.1 (S), Q3.2 (S), Q3.3 (S), Q4.2 (E), Q8.1 (S), Q8.2 (S), Q8.3 (S), R2.2, STM_C1.1, STM_C2.1, STM_C3.1, STM_C4.1, STM_C5.1, STM_C6.1, STM_C7.1, STM_C8.1, STM_C9.1, STM_C10.1, STM_R3.1, SW1.1, U1.8 (VSSA), U1.23 (VSS), U1.35 (VSS), U1.47 (VSS), U2.8 (FSYNC), U2.9 (GND), U2.10 (GND), U2.11 (GND), U2.12 (GND), U2.13 (GND), U2.15 (GND), U3.1 (GND), U3.7 (GND), U4.1 (GND), U4.10 (GND), U4.12 (GND), U5.4 (PGND), U5.8 (PS), U5.9 (GND), U5.11 (EP), U7.7 (VEE), U7.8 (GND), U8.1 (GND), U9.4 (GND), U10.4 (GND), U11.4 (GND), U12.2 (GND), U13.4 (GND), Y1.2, Y1.4
GPS_RF: J5.1 (In), L1.1, U4.11 (RF_IN)
GPS_RX: U1.13 (PA3), U4.2 (TXD1)
GPS_TX: U1.12 (PA2), U4.3 (RXD1)
ICM_CS: ICM_R1.2, ICM_R3.2, U2.5 (~CS)
ICM_INT: U1.31 (PA10), U2.6 (INT)
LED_STATUS: D5.4 (DIN), J8.3, U1.20 (PB2)
MUL_AN: U1.10 (PA0), U7.3 (A)
MUL_E~: U1.45 (PB8), U7.6 (~E)
MUL_S0: U1.2 (PC13), U7.11 (S0)
MUL_S1: U1.3 (PC14), U7.10 (S1)
MUL_S2: U1.4 (PC15), U7.9 (S2)
NRST: NRST_C1.1, STM_R1.1, U1.7 (NRST)
unnamed: BATT3S2_Q2.1 (B), BUZ_R1.2
unnamed: BATT3S2_Q2.3 (C), BZ1.2 (+)
unnamed: BUZ_R2.2, BZ1.1 (-)
unnamed: BATT3S2_R6.2, D3.2 (A)
unnamed: D4.1 (K), ICM_C1.2, ICM_C2.2, U2.1 (VDDIO), U2.16 (VDD)
unnamed: BATT3S2_R4.2, D16.2 (A)
unnamed: BT_R2.1, E1.23 (KEY), JP2.1 (A)
unnamed: BT_R1.1, E1.24 (LED)
unnamed: BT_C1.1, BT_R3.2, E1.11 (RESET)
unnamed: GPS_R2.1, L1.2
unnamed: D8.5 (K), J4.7 (DAT0), SDC_R5.2
unnamed: J6.2, Q8.5 (D)
unnamed: J7.2, Q3.5 (D)
unnamed: F3.2, J9.1
unnamed: F2.2, J11.1
unnamed: J12.2, SW1.2, U11.2 (*PB)
unnamed: JP1.2 (B), RSTM_R2.2
unnamed: JP3.2 (B), JP4.2 (B), LTC_R2.1
unnamed: BATT3S2_R7.2, LED_3S2_ON1.2 (A)
unnamed: LED_3V3.2 (A), PWR_R1.2
unnamed: 5V_R3.2, LED_5V1.2 (A)
unnamed: BATT3S2_R6.1, LED_14V8.2 (A)
unnamed: BT_R1.2, LED_BT1.2 (A)
unnamed: LED_PYRO_0.2 (A), PYR_R15.2
unnamed: LED_PYRO_0.1.2 (A), PYR_R13.2
unnamed: LED_PYRO_1.2 (A), PYR_R16.2
unnamed: LED_PYRO_1.1.2 (A), PYR_R14.2
unnamed: PYRO_Q3.1 (B), PYR_R9.1, PYR_R18.2
unnamed: PYRO_Q3.2 (E), PYR_R19.2, Q3.4 (G)
unnamed: PYRO_Q211.1 (B), PYR_R2.1, PYR_R3.2
unnamed: PYRO_Q211.2 (E), PYR_R17.2, Q8.4 (G)
unnamed: BATT3S2_R2.2, BATT3S2_R3.2, Q4.1 (B)
unnamed: PYR_R5.2, PYR_R6.1, Q6.1 (B)
unnamed: PYR_R4.2, Q6.2 (E)
unnamed: STM_C10.2, STM_R4.2, Y1.3
unnamed: SDC_R2.1, U1.14 (PA4)
unnamed: SDC_R4.1, U1.15 (PA5)
unnamed: SDC_R3.1, U1.17 (PA7)
unnamed: BMP_R2.1, U1.29 (PA8)
unnamed: ICM_R3.1, U1.25 (PB12)
unnamed: SPI_R2.1, U1.26 (PB13)
unnamed: SPI_R3.1, U1.28 (PB15)
unnamed: ICM_C4.1, U2.14 (REGOUT)
unnamed: ICM_R2.1, U2.4 (SAO/SD0)
unnamed: BMP_R3.1, U3.5 (SDO)
unnamed: GPS_C4.2, GPS_R1.1, U4.9 (RESET)
unnamed: FB1.1, GPS_C1.2, GPS_C2.2, U4.6 (V_BCKP), U4.8 (VCC)
unnamed: GPS_R2.2, U4.14 (VCC_RF)
unnamed: LPWR_L1.2, U5.3 (L)
unnamed: PWR_R2.2, PWR_R3.1, U5.7 (UVLO)
unnamed: PWR_C3.1, U5.1 (VAUX)
unnamed: U10.2 (1B), U10.3 (2Y)
unnamed: LTC_C2.1, LTC_R2.2, U11.8 (*KILL)
unnamed: LTC_C4.1, U11.3 (ONT)
unnamed: LTC_C3.1, U11.7 (PDT)
unnamed: U13.6 (2B), U13.7 (1Y)
unnamed: U9.2 (1B), U9.5 (2A), U13.3 (2Y)
PD0: STM_C9.2, U1.5 (PD0), Y1.1
PD1: STM_R4.1, U1.6 (PD1)
PYRO_AN0: PYR_C1.1, PYR_D1.2 (A), PYR_R7.2, U7.13 (A0)
PYRO_ON0: JP5.1 (A), PYR_R15.1, U1.40 (PB4), U9.1 (1A)
PYRO_ON0.1: JP5.2 (B), PYR_R2.2, PYR_R13.1, U9.7 (1Y)
PYRO_ON1: JP7.1 (A), PYR_R16.1, U1.41 (PB5), U9.6 (2B)
PYRO_ON1.1: JP7.2 (B), PYR_R9.2, PYR_R14.1, U9.3 (2Y)
PYRO_TEST~: PYR_R6.2, U1.38 (PA15), U13.2 (1B)
RFD_RX: D1.3 (K), J1.3, U1.43 (PB7)
RFD_TX: D1.2 (K), J1.2, U1.42 (PB6)
SDC_CS: D8.3 (K), J4.2 (CD/DAT3), SDC_R1.1, SDC_R2.2
SPI1_MISO: SDC_R5.1, U1.16 (PA6)
SPI1_MOSI: D8.1 (K), J4.3 (CMD), SDC_R3.2
SPI1_SCLK: D8.4 (K), J4.5 (CLK), SDC_R4.2
SPI2_MISO: BMP_R3.2, ICM_R2.2, U1.27 (PB14)
SPI2_MOSI: SPI_R3.2, U2.3 (SDA/SDI), U3.3 (SDI)
SPI2_SCLK: SPI_R2.2, U2.2 (SCL/SPC), U3.4 (SCK)
SYS_SWCLK: J2.2, U1.37 (PA14)
SYS_SWDIO: J2.1, U1.34 (PA13)
SYS_TRACESWO: J2.4, U1.39 (PB3)
USB_D+: U1.33 (PA12), U12.4 (I/O2), USB_R1.1
USB_D-: U1.32 (PA11), U12.6 (I/O1)
USB_D_CON+: J3.3 (D+), U12.3 (I/O2)
USB_D_CON-: J3.2 (D-), U12.1 (I/O1)
USB_VBUS: FB2.2, ICM_C6.2, ICM_C7.2, J3.1 (VBUS)
VCC: D6.1 (K), JP3.1 (A), LPWR_L1.1, LTC_C1.1, LTC_R1.2, PWR_C2.1, PWR_R2.1, Q2.2 (S), U5.5 (VIN), U11.1 (VIN)
VDD: D6.2 (A), FB2.1, ICM_C5.2, Q2.1 (G), R2.1, RDX_D1.2 (A), U12.5 (VBUS)

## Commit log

2023-10-09 Add BOM file
    [ODB1.xlsx]
2023-10-09 add image and BOM
    [ODB1.xlsx]
2024-01-26 Add base firmware
    [block.kicad_sch, io.kicad_sch, main.csv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]
